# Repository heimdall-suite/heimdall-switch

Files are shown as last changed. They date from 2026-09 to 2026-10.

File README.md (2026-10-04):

# heimdall-switch

Wireless power switch node for RC vehicles, part of the [Heimdall Suite](../heimdall-kickoff.md).

Controlled from `heimdall-module` over BLE, independent of the vehicle's
normal RC control link (e.g. CRSF) — this switch has its own out-of-band
radio path so it keeps working regardless of the state of the main control
link. It originated as a replacement for a boat's Jeti SPS-20 magnetic
switch, but is built as a generic building block (not a single-purpose
commercial part like Jeti's RCPS10) so the same design serves any RC
vehicle — boat, plane, car — needing a remotely switched load.

## How it's triggered

```mermaid
flowchart LR
    TX["EdgeTX transmitter<br/>Lua widget or OneClick"]
    BTN["Local button<br/>on the switch node"]
    MOD["heimdall-module<br/>external RF module (ESP32-C3)"]
    SW["heimdall-switch<br/>nRF52 node"]
    LOAD["Switched load"]

    TX -- "S.Port" --> MOD
    MOD -- "BLE command (absolute ON/OFF)" --> SW
    SW -- "MOSFET (fail-on)" --> LOAD
    SW -- "BLE ack burst" --> MOD
    MOD -- "S.Port telemetry (ack)" --> TX
    BTN -. "5-15s: toggle, 15s+: pair" .-> SW
```

The transmitter side (Lua widget or a OneClick action) sends the command
through `heimdall-module`, the external RF module in the transmitter's
module bay; `heimdall-module` relays it over BLE to `heimdall-switch`,
which drives the MOSFET and acks back the same path so the widget can
show "Hello" / "Goodbye" / "No response". The node also has a local button
for manual toggling and pairing, independent of that whole chain.

## Docs

- [.docs/hardware.md](.docs/hardware.md) — MCU, power, switching stage,
  feedback, button/LED, open hardware items
- [.docs/protocol.md](.docs/protocol.md) — BLE roles, pairing, runtime
  cycle, command/ack frame layouts, the transmitter-side Lua widget
- [.docs/persistence.md](.docs/persistence.md) — what's kept in flash
  across power loss (state + replay counter) and the wear-levelling scheme
- [.agents/AGENTS.md](.agents/AGENTS.md) / [CLAUDE.md](CLAUDE.md) —
  instructions for AI coding agents working in this repo
- [hardware/kicad/](hardware/kicad/) — first-draft KiCad schematic (see
  `.docs/hardware.md`'s Schematic section for what's in it and what's
  still a placeholder)

## Status

No firmware yet. nRF52 toolchain (nRF5 SDK vs. nRF Connect SDK/Zephyr vs.
upstream Zephyr) is not yet decided. `src/` is a placeholder until that's
settled. A first-pass schematic exists under `hardware/kicad/`.

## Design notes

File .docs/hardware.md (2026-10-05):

# Hardware

- **MCU**: nRF52 — nRF52-DK or Adafruit Feather nRF52 Bluefruit for dev;
  production target is the **Fanstel BT832** module (nRF52832, 14×16×1.9mm,
  integrated PCB trace antenna, no custom RF layout needed). Chosen over the
  smaller Insight SiP ISP1507 (8×8×1mm) specifically for assembly: the
  ISP1507 is a 62-pad bottom-only LGA with no side access, which needs
  stencil+paste reflow — not viable for hand rework. The BT832 instead
  breaks out 16 pins as **castellated edges** (side-accessible, and per
  Fanstel's own datasheet, "SMT equipment is not required for soldering
  castellated pins"), backed by 24 further LGA-only pins for full 32-GPIO
  access if ever needed. Every signal this design needs — VDD, GND,
  SWDCLK/SWDIO/RESET for programming, plus 2 analog-capable GPIOs
  (P0.02/AIN0, P0.03/AIN1) and enough spare digital GPIOs for the output
  OFF-hold drive, ADC feedback, the button interrupt, and the status LED —
  lands on those 16 castellated pins, so the LGA-only pads never need to be
  used. A same-footprint BT832F variant (15×20.8×1.9mm, ~760m vs ~110m
  range) exists if longer BLE range is ever needed; not required for this
  short vehicle-to-module link, so BT832 is the default unless that changes.
- **Radio**: BLE. Chosen over ESP-NOW/WiFi-class radios (too power-hungry to
  listen continuously, ~mA-range RX current with no good sleep/wake story)
  and over sub-GHz CC1101 (lower idle current in theory, but needs its own
  antenna design and a second discrete radio chip — not worth it once
  duty-cycle math showed BLE was already more than adequate).
- **Power**: 2S-3S LiPo (~6-12.6V) off the vehicle's own power bus. Regulator:
  **TI TPS629206** (verified against the actual datasheet — 3-17V in, 4µA
  typical IQ, 0.6A max output — same TPS6292xx low-IQ family as the
  originally-considered TPS62901, ~30x this design's actual peak draw) —
  single stage is sufficient; a pack this size (1500-2500mAh) gives years
  of idle life even at a few µA, so don't over-engineer the regulator stage
  further. Chosen over the TPS62901 specifically for assembly: TPS62901 is
  only offered in a 9-pin VQFN-HR (0.5mm pitch, no-lead, recessed pins —
  reflow/hot-air-only with no visible solder joint), while the TPS629206 is
  in an **8-pin SOT-5X3 (1.6×2.1mm) with genuine gull-wing leads** (confirmed
  from the package outline's lead foot-angle dimensions) — same 4µA
  efficiency, no assembly trade-off. Full reference-design BOM below.
- **Switching element**: single high-side P-FET, **fail-on** — see
  [Switching stage](#switching-stage) below. No mechanical or coil relays.
  State across power loss is kept in flash
  ([persistence.md](persistence.md)), the same approach the Jeti SPS-20
  takes (MCU-driven FET switch with remembered state).
- **Feedback**: resistor divider on the switched (load-side) output into an
  ADC pin, to confirm actual delivered power downstream — not just "we sent
  a pulse."
- **Local button**: debounced, GPIOTE interrupt-wake (must wake the nRF52
  from deep sleep independent of the normal BLE scan cycle). Held ≥5s but
  <15s → toggle power state locally. Held ≥15s → enter pairing mode.
- **Status LED**: 1 GPIO, visual state indicator. Must be clearly visible
  **outdoors in sunlight**, typically through a 3mm hole drilled in the
  hull/fuselage (as with the Jeti SPS-20's daughter-board LED). So: 3mm
  through-hole, water-clear lens, narrow beam, high intensity — **Kingbright
  L-7104ZGCK**, InGaN green 525nm, 8cd min / 14cd typ at 20mA, 30° (see
  [BOM](#bom)). Originally the Everlight 204-10SUGC/S400-A4 (3.2cd, 20°),
  which went out of stock at TME and Mouser; it's still the LCSC alternative.
  - **Driven from VBAT, not 3.3V**: high-intensity green/blue/white LEDs
    (InGaN) need ~3.0-3.4V forward, which leaves nothing across a
    resistor on the 3.3V rail. Circuit, **high-side switched** so the
    LED's cathode can go straight to GND (3 daughter-board wires, not 4):
    VBAT → Q6 (BSS84 P-FET) → R_LED (680Ω 1206) → LED → GND. Q6's gate is
    pulled up to VBAT by R_Q6_PU (1MΩ) and pulled to GND by Q5 (AO3400A)
    when P0.03 (`LED_DRV`) is high, giving Q6 |V_GS| = full pack voltage
    (within BSS84's ±20V). R_LED_PD (1MΩ) holds Q5 off while the MCU is
    in reset or dead. Plain GPIO drive; no high-drive mode needed. Cost:
    ~6-13µA through R_Q6_PU *only while the LED is lit*; nothing when off.
    Q6 is the same part as Q2 and Q5 as Q1, so no new part numbers.
  - **Current follows pack voltage** (V_F ≈ 3.1V at these currents):
    ~4.3mA at 6.0V (2S LiFePO4 near empty), ~5.1mA at 6.6V (2S LiFePO4
    nominal), ~7.8mA at 8.4V (2S LiPo full), ~14mA at 12.6V (3S full) —
    roughly 1.7-10cd with the L-7104ZGCK (intensity is linear in current
    on its datasheet curve; 25mA max), far above a normal indicator. R_LED
    dissipates ≤0.13W. If an even brightness matters, firmware can PWM
    the LED against the pack voltage it reads through ADC_FB while the
    output is ON.
  - **Short protection**: Q6 and R_LED sit on the main board ahead of J4, so a
    daughter-board wire shorted to GND draws at most 12.6V / 680Ω =
    18.5mA (0.23W, within the 1206's 0.25W).
- **Breakout for a daughter board (J4)**: LED and button can sit on the
  main board (LED1/SW1 fitted) or on a small daughter board, positioned
  wherever the vehicle needs them. J4 is a 3-pin **JST-GH** header
  (SM03B-GHS-TB, 1.25mm pitch, right-angle SMD at the board edge; 1 LED_A,
  2 BTN, 3 GND — the LED cathode and the
  button share the GND wire) wired in parallel with LED1/SW1. In the main
  schematic LED1/SW1 are the *optional on-board positions*; for off-board
  use leave them unfitted and plug a ready-made 3-wire GH cable
  (pin 1 ↔ pin 1) from J4 to the daughter board's GH header. Q5, Q6 and
  R_LED stay on the main board, so the daughter board only needs the LED
  and the switch. See [Daughter board](#daughter-board-ui).
  **R_BTN (1kΩ)** in
  series with P0.20 protects the pin from ESD on the off-board wire (the
  button is the part people touch); with the internal pull-up (~13kΩ) the
  pressed level is ~0.23V, a clean logic low.

## Pin assignment (BT832 castellated edge)

All 16 castellated pins are used or reserved; the 24 LGA-only pads are
untouched. Programming pins (VDD/GND/RESET/SWDCLK/SWDIO) are covered in
[protocol.md](protocol.md)'s scope — this table is the full picture:

| Pin | Net | Function |
|---|---|---|
| 1 | P0.26 | Spare GPIO (was the LED drive; moved to P0.03 so PCB traces from this pin row don't cross the crystal) |
| 2 | P0.27 | Spare GPIO |
| 3 | P0.00/XL1 | 32.768kHz crystal (LFCLK) |
| 4 | P0.01/XL2 | 32.768kHz crystal (LFCLK) |
| 5 | P0.02/AIN0 | ADC feedback (load-side sense divider) |
| 6 | P0.03/AIN1 | Status LED drive (`LED_DRV`, Q5 gate; high = LED on) |
| 7 | P0.09 | Spare GPIO (NFC pin — needs `NFCPINS` UICR cleared to use as GPIO) |
| 8 | P0.10 | Spare GPIO (NFC pin — needs `NFCPINS` UICR cleared to use as GPIO) |
| 9 | VDD | Power |
| 10 | GND | Ground |
| 11 | P0.13 | Output OFF-hold (high = output OFF, released = ON) |
| 12 | P0.18 | SWO (trace output to J1 pin 6) |
| 13 | P0.20 | Button input (GPIOTE, must wake from System OFF) |
| 14 | P0.21/RESET | SWD reset |
| 15 | SWDCLK | SWD clock |
| 16 | SWDIO | SWD data |

Notes:
- **LFCLK**: the module's mandatory 32MHz radio crystal is already onboard
  the BT832 (not exposed on any pin). Pins 3/4 are for the *optional*
  32.768kHz LFCLK crystal. It is **not required**: this node only scans
  and advertises (no BLE connections), and neither needs better than the
  internal RC oscillator's ±500ppm — drift over a 2.5s wake interval is
  ~1ms. The crystal is a small idle-power optimization (Fanstel's datasheet
  recommends it "for lower power consumption at idle state"): the RC
  oscillator draws more (~0.6µA vs ~0.25µA for the crystal oscillator,
  nRF52832 PS typicals — verify) and needs periodic calibration against
  the 32MHz crystal (cheap here: it can piggyback on the scan wake-ups).
  Net saving ~0.4-0.7µA, i.e. 1-2% of the ~34µA OFF budget — hard to
  justify on power alone. **Decision: Y1/C1/C2 stay in the design;
  whether to fit them is decided at assembly.** Firmware must therefore
  support both LFCLK sources (LFXO and calibrated LFRC), ideally
  detecting which is present; with the crystal fitted, the real
  difference can be measured at bring-up. Part: **Epson FC-135** 32.768kHz, CL 12.5pF, ±20ppm
  (3.2×1.5mm, Mouser FC-135 32.7680KA-A5 / LCSC C32346 (JLCPCB basic);
  the 9pF variant isn't stocked),
  with C1 = C2 = **18pF C0G**: nRF52 formula C = 2·CL − C_pin (4pF) −
  C_pcb (~1-2pF) ≈ 19-20pF → nearest E12 below.
- **DC/DC**: the two inductors for the nRF52832's internal DC/DC regulator
  are inside the BT832 module (per Fanstel's datasheet), so firmware can
  enable DC/DC mode — the lower-current figures in the power budget apply.
- **P0.09/P0.10** default to NFC antenna function at reset; firmware must
  clear the `NFCPINS` UICR register once to use them as plain GPIOs. No
  hardware-side implication, just a firmware bring-up step to remember.
- Programming header: pins 9/10/14/15/16 (VDD/GND/RESET/SWDCLK/SWDIO) are
  grouped on the same edge of the module — worth breaking out to a small
  pogo-pin test-jig footprint or header for repeated flashing during
  bring-up, rather than hand-wiring each time.
- **SWD header J1**: the standard **ARM Cortex Debug 10-pin** connector
  (2×5, 1.27mm pitch), male pins on the board, the probe's ribbon cable
  brings the female socket. J-Link, ST-Link, the Raspberry Pi Debug
  Probe, CMSIS-DAP probes and Nordic DKs' debug-out all plug straight in.
  **hanxia HX PZ1.27-2x5P TP** (SMD, LCSC C41376037, ~$0.10), a generic
  2×5 1.27mm SMD header. The Samtec FTSH-105-01-L-DV-K (C5155080) that
  ARM's spec references is the same thing at ~$1.46. Its recommended land
  pattern (0.74 × 2.50mm pads, 6.50mm overall) matches KiCad's
  `PinHeader_2x05_P1.27mm_Vertical_SMD` (0.74 × 2.40mm, 6.30mm overall,
  same 1.5mm gap between rows) closely enough to keep the stock
  footprint. Ordered part: **Connfly DS1031-08-2\*5P8BS41-3A** (TME
  ZL322-2X5P), since TME doesn't carry the hanxia. Its recommended land
  pattern (0.60 × 2.45mm pads, 1.60mm between rows, 6.50mm overall, tails
  spanning 5.7mm) is also within ~0.1mm of the stock footprint, and the
  drawing has no locating pegs (only an optional pick-up cap). Fitted on
  **every** board: each one needs SWD at least once
  to flash the bootloader, and later for recovery. It's unshrouded, so
  the cable can go on either way round: pin 1 is marked on the
  silkscreen, match it to the ribbon's red stripe. Programmer: the nRF52
  DK's Debug out (P19, same 10-pin connector) or any J-Link/CMSIS-DAP
  probe, with a plain 10-pin 1.27mm ribbon cable.

  | J1 pin | Signal | BT832 pin |
  |---|---|---|
  | 1 | VTref (+3V3) | 9 (VDD) |
  | 2 | SWDIO | 16 |
  | 3, 5, 9 | GND (9 = GNDDetect) | 10 |
  | 4 | SWCLK | 15 |
  | 6 | SWO | 12 (P0.18) |
  | 7 | KEY (no pin function) | — |
  | 8 | NC/TDI (not connected) | — |
  | 10 | nRESET (10k pull-up R_RST to +3V3) | 14 (P0.21/RESET) |

  SWO is the nRF52832's trace output, fixed to P0.18 in silicon: wiring
  it gives printf-style logging over the debug probe (e.g. SEGGER SWO
  viewer) without a UART. P0.18 was spare, so it costs nothing.

  Pin 1 is a **voltage reference for the probe, not a power input** — power
  the board from its battery while flashing. A probe set to *supply*
  3.3V with no battery connected back-feeds through the buck onto VBAT,
  and with fail-on Q3 then puts ~3V on the load output.
- 4 spare GPIOs remain (1, 2, 7, 8) if anything else comes up.
- P0.13 must be driven to its saved state as early as possible in boot —
  see [Switching stage](#switching-stage).

## Switching stage

**Load**: receiver, GPS, 4 micro/mini servos, 2 standard servos, on 22-24
AWG leads. ~2-3A continuous, ~6-8A peaks for tens of ms (servos
starting/stalling together). Output is raw pack voltage (up to 3S /
12.6V) — with 3S, a BEC sits downstream of the switch. Nothing else may
feed the output side (no receiver-side battery, no ESC BEC red wire): a
single FET's body diode conducts output→input when off, so back-feed would
defeat the switch. Back-to-back FETs were considered and dropped for this
reason — not needed as long as that rule holds.

**Fail-on principle**: a control-side failure must never kill the output
— losing power in flight/on the water means losing the vehicle. The
hardware default is therefore ON, and the MCU must *actively hold* the
output OFF. The realistic failure causes are firmware hangs, brownout
resets, vibration-cracked solder joints, regulator failure — spontaneous
silicon failure is negligible by comparison — and all of these fall back
to ON. Only a failure in the power path itself (the FET, its gate
pull-down) can drop the output; MOSFETs typically fail short (ON), which is
the benign direction.

**Circuit**:
- **Q3 — load switch**: P-FET, source to VBAT, drain to LOAD_OUT.
  **Selected: AOS AO4407A** (SO-8, LCSC C16072) — −30V V_DS, ±25V V_GS,
  R_DS(on) ≤ 13mΩ at V_GS = −10V, ≤ 17mΩ at −6V (12.7mΩ typ), V_GS(th)
  −1.7 to −3.0V. It is *not* specified at −4.5V, and doesn't need to be:
  the gate is pulled all the way to GND, so |V_GS| = pack voltage, never
  below ~5V on 2S (≈14mΩ typ there per datasheet Fig. 5). Worst case at
  3A ≈ 0.15W; peaks ~1W for ms — fine in SO-8 with a copper pad. Chosen
  over the DFN 3×3 AONR21357 (C431196, ≤12.3mΩ at −4.5V) for easier hand
  assembly/inspection on pre-production boards — AONR21357 is the drop-in
  electrical upgrade if the board is shrunk later. AO4409 (SO-8, −4.5V
  spec) rejected: obsolete. SOT-23 parts (typically 40-60mΩ) run too hot
  at 3A continuous.
- **Gate default ON**: Q3 gate pulled to GND by R_PD1 ‖ R_PD2 (2×2.2MΩ =
  1.1MΩ), split so a single open resistor can't leave the gate floating.
- **Slow turn-on**: C_SS = 220nF gate-source with the 1.1MΩ pull-down →
  τ ≈ 240ms. On battery connect or MCU reset the gate starts at V_GS = 0;
  Q3 only starts conducting once V_GS crosses its threshold. Simulated
  (see [Verification](#verification-simulation-and-copper)) across the
  AO4407A's threshold spread (−1.7 to −3.0V): **40–70ms after power-up at
  12.6V, 60–115ms at 8.4V** (AOS's own model: 92 / 153ms). The MCU must
  assert OFF before that — the firmware requirement stays **within ~20ms
  of power-up** (bare nRF52 boot to GPIO is a few ms), leaving ≥2× margin.
  Q3 then passes through its linear region in ~12–40ms, fully on after
  ~75ms at 12.6V / ~115ms at 8.4V.
  The same RC soft-starts the inrush into the downstream
  BEC/receiver/servo capacitance.
  C_SS is a **50V X7R 0805** (Samsung CL21B224KBFNNNE, LCSC C5378), not a
  25V 0603: it sits at up to 12.6V, and a 25V 0603 X7R loses ~30% of its
  capacitance there, cutting the delay by about as much. The 50V 0805
  part loses ~10%. Don't reduce C_SS: 100nF would bring the worst case
  down to ~19ms, inside the firmware window (simulated).
- **Active OFF**: Q2 (P-FET) clamps Q3's gate to VBAT through R_LIM when
  on. Q2's gate is pulled up to VBAT by R_CLAMP_PU (1MΩ) and pulled low by
  Q1 (N-FET), driven from P0.13 via R_G1 (100Ω), with R_OFF_PD (1MΩ)
  holding Q1 off whenever the GPIO floats (reset, unpowered MCU). GPIO
  high → Q1 on → Q2 on → output OFF. Turn-off is fast (~30–40µs,
  simulated); only turn-on is slowed.
  - **Q1: AOS AO3400A** (SOT-23, LCSC C20917, JLCPCB basic part) —
    logic-level (V_GS(th) 0.65-1.45V), fully on from a 3.3V GPIO. The CJ
    2N7002 (C8545, V_GS(th) up to 2.5V) was the placeholder: works, but
    thin margin at 3.3V drive.
  - **Q2: Nexperia BSS84** (SOT-23, LCSC C493579) — V_GS(th) −0.8 to
    −2.0V, I_DSS ≤ 100nA at −40V/25°C. A *high* threshold is deliberate:
    the more gate voltage Q2 needs, the more Q1 leakage it takes to turn it
    on by accident (so low-threshold parts like AO3401A are unsuitable
    here). **Ordered: Nexperia BSS84AK** (TME; the BSS84 is out of stock
    at TME and Mouser, and Mouser lists it as not recommended for new
    designs): same SOT-23 G/S/D pinout, V_GS(th) −1.1 to −2.1V (higher, so
    better here), ±20V V_GS, ESD-protected gate (I_GSS ≤ 10µA at ±20V,
    which only flows while Q1 holds the gate low). Its I_DSS spec is
    looser — ≤ 1µA at −50V/25°C, ≤ 2µA at 150°C — still below the ≈3-9µA
    step (2) below needs, but one more reason to do the first-board check.
  - **R_LIM (100Ω, Q2 drain → Q3 gate)**: when Q2 switches on it shorts
    C_SS (charged to VBAT); without R_LIM the discharge spike is ~1A+ for
    ~µs, above BSS84's ~0.5A pulse rating (tiny energy, ~17µJ — a spec
    violation rather than a likely failure). R_LIM caps it at ~0.1A;
    turn-off goes from ~2µs to ~20µs, irrelevant for this load.
- **Leakage margin for fail-on**: with the MCU dead, a chain of leakages
  would have to (1) pull Q2's gate ~0.8-1V below VBAT — ≈1µA of Q1
  leakage through R_CLAMP_PU — and then (2) push ≈3-9µA through Q2 into
  Q3's gate against R_PD (1.1MΩ) to lift it within ~3V of VBAT. Small
  SOT-23 FETs typically leak tens of nA at 7-13V and warm temperatures:
  10-100× margin. Datasheet worst cases (often "1µA max" at full rated
  V_DS) are looser, so **verify on the first boards**: MCU unpowered,
  output ON — Q3 gate should read within a few mV of GND and Q2 gate
  within a few mV of VBAT. Don't raise R_CLAMP_PU / R_PD further to save
  current without re-checking this.
- **Gate protection**: D_Z, 18V zener gate-source on Q3 (cathode to VBAT)
  — **MMSZ5248B** (SOD-123; ordered from DC Components via TME, LCSC
  C2127 is JSCJ's). At 12.6V max the ±25V gate
  is within spec without it; it's cheap insurance against transients.
  18V rather than 15V because the zener sits reverse-biased at full pack
  voltage whenever the output is ON, and its leakage flows into Q3's gate
  node against R_PD: a 15V zener at 12.6V (84% of V_Z) is near its knee
  and can leak µA, lifting the gate; the 18V part is specified at
  ≤100nA at 14V (≤0.11V gate lift through 1.1MΩ), and still clamps well
  below the 25V gate rating.

**Reverse polarity protection**: servo-style RC plugs are easy to insert
backwards, and a reversed pack would destroy not just this node but the
load — Q3's body diode would conduct and put reversed voltage across the
receiver/servos. So the protection covers the whole power path, right at
the battery input:
- **Q4**: P-FET "ideal diode" in the positive line between J3 and the VBAT
  rail — drain to the battery (+) pin of J3, source to VBAT, gate to GND
  via R_REV (100kΩ), plus an 18V gate-source zener (D_Z2, cathode to
  source, same MMSZ5248B) like Q3's. **Same part as Q3: AO4407A** (SO-8, LCSC C16072).
- Correct polarity: Q4's body diode conducts first, lifting its source to
  ~VBAT, which pulls V_GS to −VBAT and turns it fully on. Reversed: the
  body diode is reverse-biased and V_GS ≈ 0, so Q4 stays off and nothing
  downstream sees negative voltage.
- Cost: zero quiescent current (no DC path below the zener voltage);
  ~135mW / ~45mV extra drop at 3A. A series Schottky was rejected — fine
  for the node's µA supply, but ~1.2W at 3A in the load path.
- Q4 only blocks *reverse polarity*. Once on, it conducts both ways, so it
  doesn't block back-feed from the output side — that's still ruled out by
  the "nothing else feeds the output" rule above.
- Out of scope: a reversed *load-side* connector (J2) can't be protected
  here — that's the load's own wiring.

**Cost of fail-on**: see [Power budget](#power-budget) — ~15µA extra while
OFF. A dead MCU while OFF turns the output ON, so a stored vehicle with the
battery connected could power up and drain the pack — **disconnect the
battery for storage** (standard practice; Jeti's SPS-20 manual says the
same).

**Firmware requirements** (see also [persistence.md](persistence.md)):
- Restore the saved state to P0.13 early in boot — within ~20ms of
  power-up, before Q3 starts conducting (see Slow turn-on).
- **Watchdog is mandatory**: firmware hung with P0.13 held high is the one
  failure the hardware default can't cover. The nRF52 WDT (LFCLK-clocked,
  can't be stopped once started) resets the MCU, which releases P0.13 →
  output falls back to ON → firmware restores the saved state.

## Power budget

Estimates, not measurements — every radio/MCU figure here needs checking on
real hardware. Reference pack: **1500mAh 2S LiFePO4 RX pack (6.6V
nominal)**. Resistor currents scale with pack voltage (roughly ×1.9 on 3S).

**Assumptions**:
- TPS629206 quiescent 4µA (datasheet typical).
- nRF52832 System ON sleep, RTC + 32kHz crystal, RAM retained: ~2µA.
- Scan cycle per [protocol.md](protocol.md): wake every 2.5s, 7.5ms scan
  window + ~1.5ms wake overhead at ~6.5mA (radio RX with the nRF52's
  internal DC/DC enabled — the BT832 has the DC/DC inductors onboard) →
  ~23µA average. LDO-mode figures below are kept only as the fallback if
  DC/DC is left disabled in firmware (RX roughly doubles → ~45µA).
- Buck efficiency at these µA loads ~85% → a 3.3V-side current appears at
  the pack as ×0.59 (3.3V / (6.6V × 0.85)).

**Always on (both states)**, at the pack:

| Item | 3.3V side | At pack |
|---|---|---|
| TPS629206 quiescent | — | 4µA |
| nRF52 sleep | 2µA | 1.2µA |
| BLE scan duty cycle | 23µA (LDO: 45µA) | 13.5µA (LDO: 26.5µA) |
| **Subtotal** | | **~19µA (LDO: ~32µA)** |

**Extra in OFF** (fail-on hold active):

| Item | Current |
|---|---|
| R_PD1‖R_PD2 across VBAT (Q2 clamping) | 6.6V / 1.1MΩ = 6.0µA |
| R_CLAMP_PU across VBAT (Q1 on) | 6.6V / 1MΩ = 6.6µA |
| R_OFF_PD on the 3.3V GPIO | 3.3µA → 1.9µA at pack |
| ADC divider (output is 0V) | 0 |
| **OFF total** | **~34µA (LDO: ~47µA)** |

**Extra in ON**: the gate network draws nothing (Q1/Q2 off, Q3 gate at
0V). The ADC divider (100k + 33k across LOAD_OUT) draws 6.6V / 133kΩ =
50µA → **ON total ~69µA** for the node itself. That's irrelevant next to
the load (receiver + GPS + 6 idle servos ≈ 150-200mA), but could drop to
~5µA with a 1M/330k divider if it ever matters (needs a longer SAADC
acquisition time for the higher source impedance).

**Storage time, OFF, battery left connected** (1500mAh pack, counted down
to 20% remaining = 1200mAh usable):

| Case | Drain | Time to 20% |
|---|---|---|
| Node only, DC/DC | 34µA | ~35,000h ≈ **4 years** |
| Node only, LDO | 47µA | ~25,500h ≈ **2.9 years** |
| Node + LiFePO4 self-discharge (~2%/month ≈ 41µA equivalent), DC/DC | ~75µA | ≈ **1.8 years** |
| For comparison: Jeti SPS-20 (160µA OFF, per its manual), node only | 160µA | ≈ 10 months |

The node's OFF draw is about the same as the pack's own self-discharge, so
leaving the pack connected costs roughly half its shelf life — acceptable,
but "disconnect for storage" still stands, mainly because of the fail-on
case above. Left **ON** by mistake, the same pack is flat in ~6-8h from
the idle load alone; the switch's own draw doesn't matter there.

Biggest levers if OFF draw needs to drop: the scan interval (2.5s → 5s
halves the ~13.5µA scan share) and the fail-on hold resistors (limited by
the leakage constraint above).

## Schematic

**Circuit at a glance** (each block is also labelled on the schematic
sheet). Four ideas explain most of it: a P-FET turns on when its gate is
pulled well below its source; an N-FET pulling a P-FET's gate down lets
a 3.3V GPIO switch a 12V path (Q1/Q2, Q5/Q6); the 1-2.2MΩ resistors set
the safe default when the MCU isn't driving (output ON, LED off); the
rest is supply plumbing.

| # | Block | Parts | Job |
|---|---|---|---|
| 1 | Battery in + reverse polarity | J3, Q4, R1, D1 | Q4 is an ideal diode: body diode lifts VBAT, R1 pulls the gate to GND, Q4 turns fully on; a reversed pack leaves it off. D1 clamps V_GS. |
| 2 | Load switch (fail-on) | Q3, R9, R10, C7, D2 | Q3 is the switch. R9 ‖ R10 hold it ON by default, C7 slows turn-on (gives the MCU time after reset), D2 clamps V_GS. |
| 3 | Switch-off circuit | Q1, R5, R6, Q2, R7, R8 | P0.13 high → Q1 on → Q2 on → R8 pulls Q3's gate to VBAT → output OFF. R6/R7 keep the chain idle when the MCU is dead. |
| 4 | Load out + voltage sense | J2, R11, R12, C8 | R11/R12 scale LOAD_OUT to the ADC (12.6V → 3.1V), C8 filters: pack voltage while ON, ~0V while OFF. |
| 5 | 3.3V regulator | R2, C3, U2, R3, L1, C4 | R2 + C3 damp the plug-in spike; U2 buck with L1/C4; R3 sets its mode. |
| 6 | MCU | U1, C5, C6, Y1, C1, C2, R4, J1 | BT832 (nRF52832 + antenna), supply decoupling, 32kHz crystal, reset pull-up, SWD header. |
| 7 | Status LED + button | Q5, Q6, R13, R14, R15, LED1, SW1, R16, J4 | P0.03 high → Q5 pulls Q6's gate low → Q6 feeds VBAT through R14 to the LED (off by default). SW1 to GND with R16 protecting the pin. J4 breaks LED/BTN/GND out to the daughter board. |

The KiCad schematic implementing everything on this page lives in
[hardware/kicad/](../hardware/kicad/) (`heimdall-switch.kicad_pro` +
`.kicad_sch`), with a rendered [heimdall-switch.svg](../hardware/kicad/heimdall-switch.svg)
for quick viewing without opening KiCad. The BT832 and TPS629206 symbols
are project-local, in `heimdall-switch.kicad_sym` (resolved automatically
via the project's `sym-lib-table`). Neither part is in KiCad's own
libraries (they have the bare nRF52832 chip, not the module), but both
have vendor symbols: Fanstel publishes a KiCad library with the BT832
([hemalchevli/Fanstel-kicad-library](https://github.com/hemalchevli/Fanstel-kicad-library),
linked from Fanstel's site; KiCad 5 format) and TI's TPS629206 symbol is
available through Ultra Librarian. Ours were drawn before those were
found and kept: the BT832 symbol's pin map is identical to Fanstel's
(checked pin by pin, see the footprint note below) and its pins sit on
KiCad's 2.54mm grid.

Drawn with real wires within each block (regulator, MCU + crystal/SWD,
status LED + button + J4 breakout, switching stage + load output), KiCad power symbols (`GND`,
`+3V3`, `VBAT` — the latter is the stock `+BATT` symbol renamed) with
PWR_FLAGs, and no-connect markers on the intentionally-open pins
(VSET/PG, spare GPIOs). Signals cross between blocks as net labels:
`OUT_OFF` (P0.13 → switching stage), `ADC_FB` (divider → P0.02),
`LED_DRV` (P0.03 → Q5 gate), `BTN` (P0.20 → R_BTN/SW1/J4), and the debug
signals `nRESET`, `SWDCLK`, `SWDIO`, `SWO` (U1 → J1).
Within the LED/button block, the `LED_A` label carries the LED anode to
J4.
J3 is the battery input connector.

Verified with `kicad-cli sch erc`, netlist export (every pin checked
against the intended net) and `sch export svg` (kicad-cli is installed
but not on PATH — `AppData/Local/Programs/KiCad/10.0/bin/`). ERC: **0
errors, 0 warnings**. All custom-symbol pins (BT832, TPS629206) sit on
the 2.54mm grid — keep it that way when editing `heimdall-switch.kicad_sym`:
an off-grid pin makes GUI-drawn wires snap past it and silently not
connect (this happened once, to SWDCLK/SWDIO).

Sheet layout: the reverse polarity block (J3 → Q4 → VBAT, with D_Z2 and
R_REV) sits on its own below the regulator and connects to it through the
`VBAT` power symbol; J3's pin 1 net is labelled `BATT+`. The debug
header J1 (with R_RST) sits in its own block right of the crystal,
linked to U1 by labels, so no wires cross.

Reading the schematic:
- **Power symbols** (`VBAT` arrow, `+3V3` arrow, `GND`) connect by name
  across the whole sheet — two `VBAT` arrows are the same net even with no
  wire between them.
- **PWR_FLAG** (small diamond, text hidden) is not a component and not in
  the BOM. It tells ERC "this net is powered from outside" — needed where
  power arrives through pins KiCad sees as passive (battery connector, Q4,
  L1, R_IN). One each on VBAT (at Q4), GND (at J3), +3V3 (at C_OUT) and
  the regulator input node after R_IN.
- One GND symbol has its "GND" text hidden where it collided with
  wires (U2 pin 5) — an ordinary GND connection.

**Annotation and footprints**: the schematic is annotated with standard
references and every part has a footprint. The design notes on this page
keep the descriptive names (`R_PD1`, `C_SS`, …); each renamed symbol
carries its old name in a hidden `Function` field, and the mapping is:

| Ref | Name in these docs | Ref | Name in these docs |
|---|---|---|---|
| C3 | C_IN | R7 | R_CLAMP_PU |
| C4 | C_OUT | R8 | R_LIM |
| C5 | C_VDD1 | R9 | R_PD1 |
| C6 | C_VDD2 | R10 | R_PD2 |
| C7 | C_SS | R11 | R_FB_TOP |
| C8 | C_FB | R12 | R_FB_BOT |
| R1 | R_REV | R13 | R_Q6_PU |
| R2 | R_IN | R14 | R_LED |
| R3 | R_MODE | R15 | R_LED_PD |
| R4 | R_RST | R16 | R_BTN |
| R5 | R_G1 | D1 | D_Z2 |
| R6 | R_OFF_PD | D2 | D_Z |

Unchanged: C1/C2 (crystal caps), Q1–Q6, U1, U2, L1, Y1, LED1, SW1, J1–J4.
Footprints are KiCad stock (0603 passives; 0805/1206 where the BOM says;
SOT-23, SOIC-8, SOD-123, SOT-583-8, 1008, 3215 crystal, JST-GH, 2×5
1.27mm SMD header, solder-wire pads) except two project-local items:
- **`heimdall-switch:Fanstel_BT832`** (in `heimdall-switch.pretty`, via
  the project `fp-lib-table`), drawn from Fanstel's datasheet (Ver 2.12,
  p.8): 14.0 × 16.0mm module, 16 castellated pads at 1.10mm pitch, pins
  1–8 down the left side and 9–16 up the right, pin 8/9 1.10mm above the
  bottom edge. Pads are 0.70 × 1.75mm, reaching 0.75mm beyond the module
  edge (and 1.0mm under it) for the soldering iron. The 24 LGA pads are left off (unused; the
  module's LGA pads then sit on solder mask). A copper keep-out (tracks,
  vias, pads, pours, both layers) covers the 6.43mm antenna section.
  **Verified against Fanstel's official KiCad library**
  ([hemalchevli/Fanstel-kicad-library](https://github.com/hemalchevli/Fanstel-kicad-library),
  MIT, linked from Fanstel's site; footprint `BT832-BT832L`): all 16 pad
  centres match within 0.001mm (pitch, pin 8/9 height, pin 1 position),
  same 0.70mm pad width and the same 0.75mm overhang beyond the module
  edge (theirs is 1.50mm long, ours 1.75mm reaching 0.25mm further under
  the module). Their symbol's pin map matches ours pin for pin.
  3D model: Fanstel's STEP of the BT832 (Pro/E export), in
  `hardware/kicad/heimdall-switch.3dshapes/Fanstel_BT832.step`, attached
  to the footprint (rotated −90° about X, raised 0.3mm so the module's
  0.6mm PCB sits on ours); total height ~2.0mm.
- **`heimdall-switch:AO4407A`** symbol (in `heimdall-switch.kicad_sym`):
  the generic P-FET drawing with SO-8 pin numbers — G = 4, S = 1/2/3,
  D = 5–8, the duplicates stacked on the same pin — so Q3/Q4 map onto the
  stock SOIC-8 footprint without moving any wires.

Verified after the change: ERC 0/0; the netlist is identical net-for-net
(old references mapped, Q3/Q4 S/D pins expanded); every symbol pin has a
matching footprint pad. Every part with an LCSC number carries it in a
hidden `LCSC` field, so `kicad-cli sch export bom --fields
"Reference,Value,Footprint,LCSC"` gives an order list. The parts
actually ordered (TME + Mouser, see [BOM](#bom)) are in hidden
`Manufacturer`, `MPN`, `Supplier` and `Supplier PN` fields; export those
the same way for the TME/Mouser order lists. Where the ordered part is a
substitute, the `LCSC` field still names the original part as the LCSC
alternative.

Known simplifications in this draft, worth revisiting before layout:
- BT832 VDD decoupling (C5 4.7µF + C6 100nF, as on Fanstel's eval
  board) sits left of U1 on the sheet; on the PCB both sit at U1's VDD
  pin.
- The switching stage implements the fail-on design in
  [Switching stage](#switching-stage) (Q1 driver, Q2 gate clamp, Q3 load
  switch, R_LIM, R_PD1/R_PD2, C_SS, D_Z).
- **The KiCad file is now the source of truth.** `gen_body.sh` /
  `build_sch.sh` generated the first wired draft, but the schematic has
  since been rearranged in the GUI and patched (J1 layout, reverse
  polarity protection, gridded symbols) — the generator no longer matches
  it. Don't run `build_sch.sh`: it would overwrite all of that. Kept only
  as a record of how the draft was produced.
- ADC divider (R_FB_TOP=100k, R_FB_BOT=33k) assumes sensing a ~12.6V max
  load rail scaled to a safe ADC input; revisit once the actual load
  voltage range is known.

## PCB layout

**Rev 2** (current), in [hardware/kicad/](../hardware/kicad/)
(`heimdall-switch.kicad_pcb`). Views:
[top](../hardware/kicad/layout-top.png),
[bottom](../hardware/kicad/layout-bottom.png) (mirrored, as seen from
below), 3D [top](../hardware/kicad/render-top.png) /
[bottom](../hardware/kicad/render-bottom.png). Status: DRC 0 violations,
0 unconnected, full schematic parity; reviewed by eye in the KiCad GUI.
Rev 1 (53 × 23mm, power path on top) was never ordered; it stays in git
under the tag `main-pcb-rev1`.

| Top, angled | Bottom (power side), angled |
|---|---|
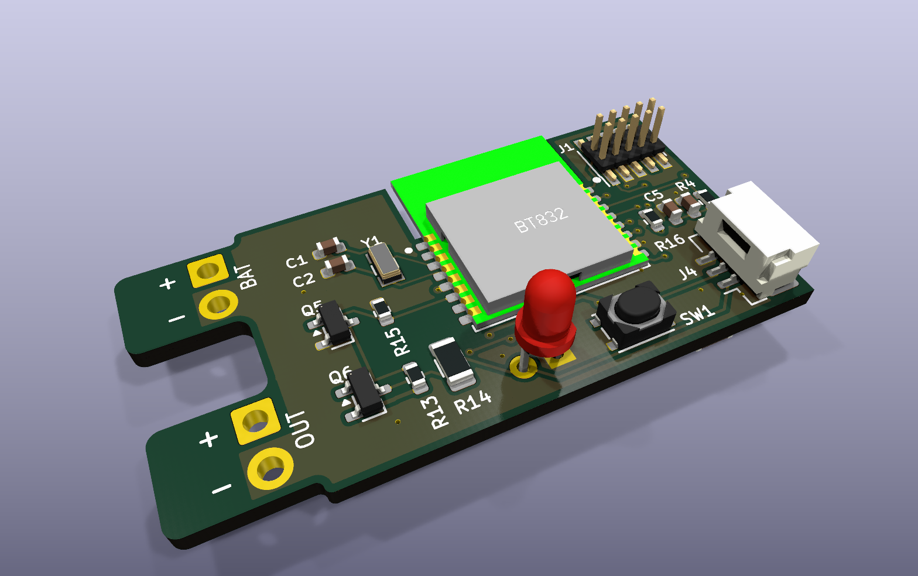
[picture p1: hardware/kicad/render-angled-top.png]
Main board, 3D top, angled
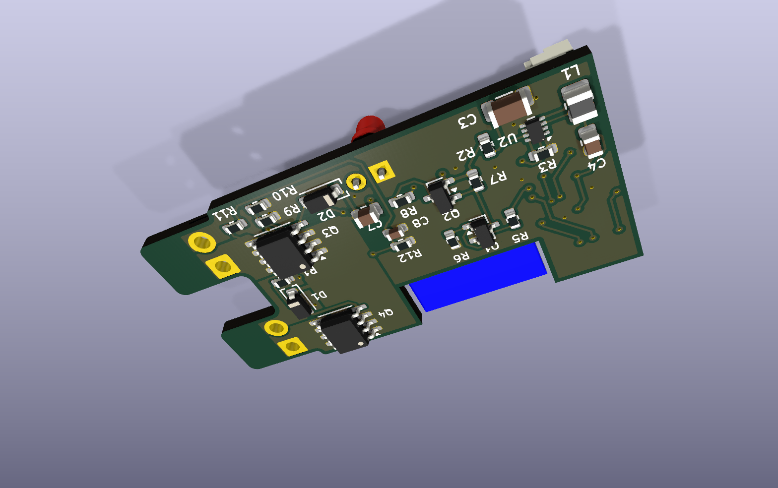
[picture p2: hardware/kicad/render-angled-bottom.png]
Main board, 3D bottom, angled
|  |  |

| Top | Bottom (mirrored, as seen from below) |
|---|---|
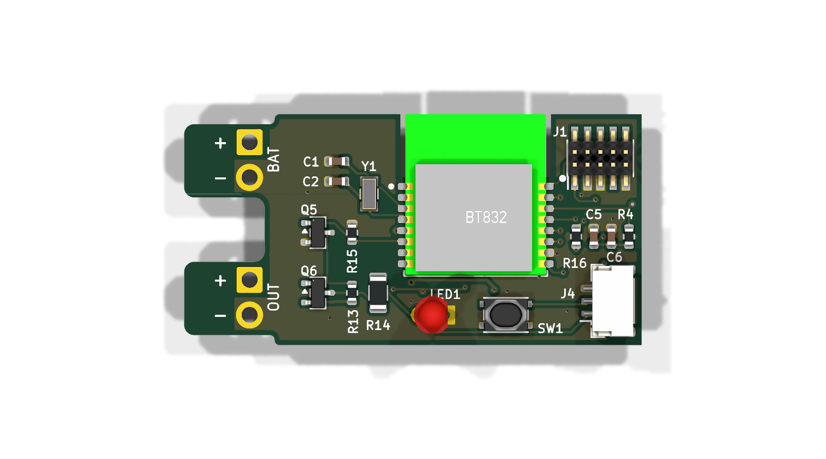
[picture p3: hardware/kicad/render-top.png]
Main board, 3D top
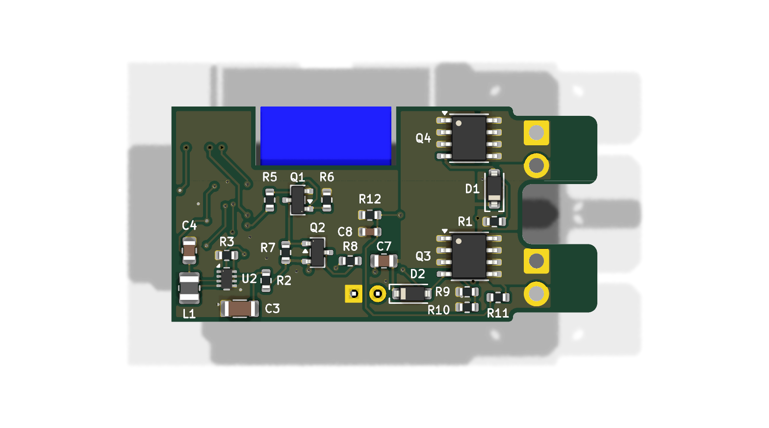
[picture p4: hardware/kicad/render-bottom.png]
Main board, 3D bottom
|  |  |
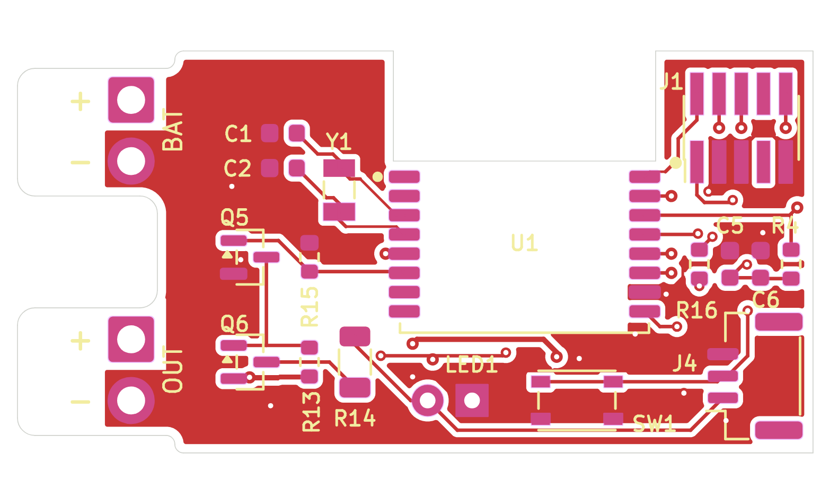
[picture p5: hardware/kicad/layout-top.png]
Main board layout, top
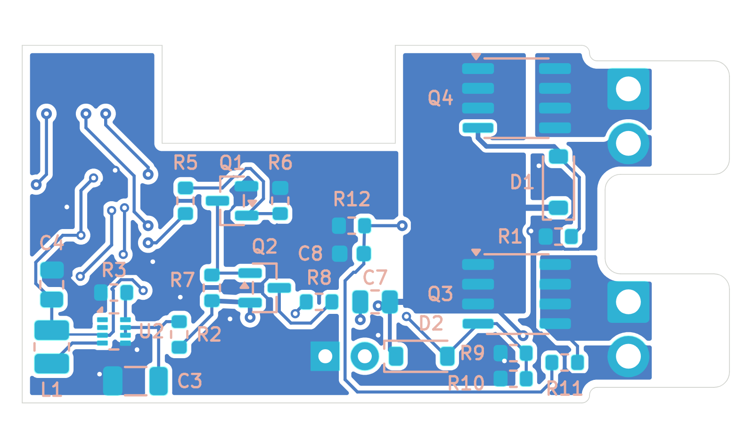
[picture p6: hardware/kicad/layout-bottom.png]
Main board layout, bottom
|  |  |

**Board**: 45.5 × 23mm, 2 layers, 1.6mm FR4, parts on both sides, laid
out in **zones by function**, like a high-voltage and a low-voltage side:
everything that carries or switches pack power (blocks 1–5 in the
[Schematic](#schematic) table) is on the **bottom**, the MCU and the
user interface (blocks 6–7) on the **top**.
- **Left end**: J3 (BAT) and J2 (OUT) wire pads, + and − of each pair
  3.5mm apart, wires entering from the left. The end is cut into **two
  symmetric tabs**, one per pair (mirror images about the board's
  centreline), as on the Jeti SPS-20: straight edges, 1mm corner radii,
  and each tab runs past its pads as bare board (no pour on either
  layer). Each pair gets its own heat shrink over tab, solder joints and
  wire insulation, so the shrink grips the board and the insulation, not
  the joints. "BAT"/"OUT" and "+"/"−" are on the top silkscreen.
- **Middle**: the BT832 at its native orientation, antenna over a
  **15 × 6.3mm notch** in the top edge (no board or copper under the
  antenna, as Fanstel recommends). Its left pin column (crystal, ADC, LED
  drive) faces the power end, the right column (debug, button, VDD) faces
  J1/J4.
- **Top side** (what you see, touch or plug in): U1; Y1 with C1/C2 in a
  column beside U1's crystal pins; the LED driver (Q5/Q6 with R13–R15)
  between the wire tabs and U1; LED1 and SW1 below the module; at the
  right end J1 (SWD header, top-right corner) and J4 (right-angle GH,
  cable entry flush with the right edge), with C5, C6 (VDD decoupling),
  R4 (reset pull-up) and R16 (button) in one row between them. **J1 stays
  on the top** (needed for the debug cable with the board in its case).
- **Bottom side** (power), left to right: Q4 with D1/R1 behind the BAT
  tab (reverse polarity), Q3 with R9/R10/C7/D2 behind the OUT tab (load
  switch), R11 in the corner below Q3; the switch-off chain (Q1, R5, R6,
  Q2, R7, R8) and the ADC divider bottom (R12/C8) under the module; the
  regulator chain R2/C3 → U2 (R3) → L1/C4 under J4. The board goes into a
  **3D-printed case**, so tall SMD parts on the bottom are fine; what
  must not stick out are through-hole leads: J2/J3 wires and LED1's leads
  are **trimmed flush** after soldering.
- **Silkscreen**: reference designators horizontal, right beside their
  part (left of it or above it where there's room), **0.85mm text /
  0.15mm stroke** throughout, rows of parts with their labels on one line.
  BAT/OUT 1.0mm, +/− 1.2mm. Values are on the fab layer only. Silk lines
  are clipped ≥0.15mm clear of pad mask openings and holes (so the
  footprints differ from the library: `lib_footprint_mismatch` is set to
  ignore in the project).

**Copper**:
- **Power path on the bottom as solid copper**: BATT+ pour (J3+ → Q4
  drain), the **VBAT bar** (pour joining Q4's and Q3's sources, ~7.9mm
  wide, with a no-tracks rule area across its middle so no other net cuts
  it in two), LOAD_OUT pour (Q3 drain → J2+).
- **GND**: pours on both layers, stitched. The **load return** (OUT− →
  BAT−) runs along the left end as a **top-side GND strap**: a no-tracks
  rule area (~6mm wide, past both − pads) filled by the F.Cu GND pour, so
  no signal can cut it. J2/J3's GND pads connect solid (no thermal
  relief), since they carry the load return. No GND pour around the + pads
  on the top (rule areas), so the + pad never sits next to GND copper.
- **No copper on top under the BT832 body** (rule area, tracks and pours):
  its unused LGA pads sit there and would only be separated from traces by
  solder mask.
- Only **45° corners** (no 90° bends).
- Net classes: Power 0.3mm (VBAT branches, BATT+, LOAD_OUT, GND traces),
  Reg 0.25mm (+3V3, regulator VIN, switch node; fits U2's 0.5mm pitch),
  Default 0.2mm; vias 0.6–0.7/0.3mm. Solder mask expansion 0.05mm
  (0.025mm on U2's 0.5mm-pitch pins, keeping 0.15mm webs). A custom rule
  (`heimdall-switch.kicad_dru`) allows neck-down to 0.15mm where traces
  enter fine-pitch pads (U1, U2), well inside JLCPCB's 0.127mm minimum.
- 40 vias in total, ~520mm of track (~215mm top, ~305mm bottom).
- **GND stitching**: 19 GND vias plus the 3 through-hole GND pads tie the
  two GND pours together. 8 of the vias (0.7/0.3mm) were added on
  2026-10-04 with `route_pcb.py gapstitch`, only where both pours are
  solid around the via and outside courtyards and keep-outs: every pour
  fragment big enough for a via now has at least 2 ties (one 5.8mm²
  bottom fragment has room for only 1), and of the ~151mm² where both
  layers have GND, 2% is more than 5mm from a tie (was 6%; worst point
  7.4mm, was 9.1mm). The regulator's and the BT832's GND pins have a tie
  within ~1mm. DRC unchanged afterwards (0 unconnected, no new
  violations). The layout pictures and 3D renders above predate these
  vias.

**Current capacity** (design target **5A continuous, 15A peaks <1s**).
Expected load, per servo: analog standard servos stall at ~0.8-1.2A
(4.8-6V); digital high-torque standard ~2.5-3.5A at 6V; HV high-torque
standard up to ~4-5A at 7.4-8.4V. Six digital servos all stalled at once
would be ~18-20A, which in practice doesn't happen; realistic peaks are
6-12A for 10-100ms when everything moves at once, with 2-5A continuous.
Short peaks barely heat copper; the continuous figure sets the width.
IPC-2221 (outer layer, 1oz/35µm, 20°C rise): 1.4mm for 3A, 2.5mm for 5A,
4.8mm for 10A. The power path's narrowest copper: BATT+ and LOAD_OUT
pours ~5.5mm, VBAT bar ~7.9mm, so roughly 10A continuous on 1oz; the GND
strap on top is ~6mm. Both − pads are plated through-holes, so the return
current changes layer in the pad barrels.
AO4407A: −12A continuous, −60A pulsed; at 10A its ~13mΩ is 1.3W, too
warm for SO-8 continuously, fine for the expected 2-5A (≤0.3W).
**2oz copper** (a JLCPCB option, extra cost) roughly doubles the copper
figures if long stalls are expected. **Decision: first iterations are
ordered with standard 1oz**; 2oz is an option for later boards. Before
switching, check JLCPCB's minimum trace/space for 2oz: heavier copper
usually raises it, and this layout has 0.15mm neck-downs at U1/U2's
pins and 0.2mm clearances, which may need widening. The wire pads take
0.75mm² (18AWG), good for ~10A in a harness.

**How it was made**: rev 2 was placed by script from the rev 1 board
(parts moved to their zones, power parts flipped to the bottom), the power
pours, rule areas and the critical runs (J1 ↔ U1 SWD fan-out, ADC lane,
VBAT/gate-drive runs) laid by hand-written scripts, the rest routed by
[Freerouting](https://github.com/freerouting/freerouting) 2.4, then
cleaned up (GND stitching, 90° corners turned into two 45° bends) and
finished by hand in the KiCad GUI. **The `.kicad_pcb` is the source of
truth**; `place_pcb.py`/`route_pcb.py` in `hardware/kicad/` are the rev 1
generators (coordinates of the earlier 63.5mm board) and don't produce
rev 2, so don't run them on it.

**Ordering (JLCPCB)**: `python jlc_export.py` (KiCad's python, from
`hardware/kicad/`) writes the whole order package to `gerber/`
(`python jlc_export.py ../kicad-ui` does the same for the UI board, into
`hardware/kicad-ui/gerber/`; see [Daughter board (UI)](#daughter-board-ui)):
- `heimdall-switch.zip`: Gerbers + Excellon drill (board plot settings:
  Protel extensions, mask subtracted from silk). Order options: 2 layers,
  1.6mm, **HASL with lead**, 1oz.
- BOM + CPL in JLC's format, three sets: both sides
  (`-BOM.csv`/`-CPL.csv`), **top only** (`-top`) and **bottom only**
  (`-bottom`), for one-sided "Economic" PCBA of either side if a batch is
  ever machine-assembled. The plan for now is bare boards and hand
  assembly; see [BOM](#bom).
- Parts without an LCSC number are left out (U1 BT832, J2/J3 wire pads):
  JLC can't place them, they're hand-soldered either way.
- **Rotation**: JLC reads bottom-side angles mirrored, so the script
  writes `180° − KiCad angle` for bottom parts (KiCad angle on top), plus
  a per-footprint correction (`ROT_OFFSET`) where JLC's 3D model doesn't
  share KiCad's zero angle (SOT-23 +180°, SOT-583-8 +270°). The
  corrections come from rev 1's placement preview, where D1/D2/U2/Q1/Q2
  sat on the bottom at 180°. **Check the placement preview every time**,
  and for rev 2 especially: **D1** (the first diode at 90° on the bottom;
  cathode band = pad 1 = the VBAT end, a reversed zener keeps Q4 off),
  D2, **Q3/Q4** (SO-8, on the bottom for the first time: pin 1 dot),
  U2, Q1/Q2.
- Position = centre of the part's pads (as JLC expects), Y negated.

**Check before ordering**:
- Simulation and copper checks: done, see
  [Verification](#verification-simulation-and-copper).
- BT832 footprint and pin map: verified against Fanstel's official KiCad
  library (see [Schematic](#schematic)). A 1:1 print with a real module on
  it is still a cheap final check if a module is at hand.
- Run JLC's DFM check on the rev 2 Gerbers (rev 1 was clean except the
  "THT to SMD" assembly rule, irrelevant for bare boards).
- Through-hole GND pads (J2/J3 pin 2, LED1 pin 1) connect solid to the
  pours (no thermal relief): use a hot iron.

## Verification (simulation and copper)

Pre-order checks of the power side, scripts in
[hardware/sim/](../hardware/sim/), run with KiCad's bundled python (it
ships ngspice): `python run_sims.py` (all circuit cases, ~10s) and
`python copper.py` (copper of the load path from the `.kicad_pcb`).
Results from 2026-10-04 on rev 2. **Nothing needed changing.**

**Circuit (ngspice)**: blocks 1–5 as in the schematic netlist (battery +
lead inductance, Q4/D1/R1, Q3 with C7/D2/R9‖R10, the Q1/Q2 OFF chain,
R2/C3 into the regulator, ADC divider, load). Every case runs on two
model sets that bracket the real part: MOSFET models fitted to the
datasheets (AO4407A 10.0/26.1mΩ at V_GS −10/−5V vs datasheet 10/27), and
AOS's own AO4407A model (downloaded by the script; 9.5/12.2mΩ at
−10/−6V vs 10/12.7). The fit has the lower threshold (earlier, slower
turn-on: pessimistic for Q3 stress), the AOS model the higher one.

| Check | Fitted models | AOS model | Verdict |
|---|---|---|---|
| Plug-in, full 3S, 0.3–2µH leads | VBAT peak 12.6V, U2 VIN 11.6V, Q3 stays off (V_GS ≈ 0) | same | No spike (R_IN, no low-ESR cap on VBAT) |
| Q3 starts conducting after power-up (C7 220nF) | 3S 40–70ms, 2S 61–114ms over V_th −1.7…−3.0V | 3S 92ms, 2S 153ms | ≥2× the 20ms firmware window; 100nF would fail it (19ms) |
| Q3 turn-on into 5A + 1000µF | 3S: 21W peak, ~21ms half-on; 2S: 11W, ~35ms | 3S: 24W, ~12ms; 2S: 12W, ~21ms | Within the AO4407A single-pulse rating (~35W at 30ms) with ~2× margin |
| Q3 turn-on into 10A + 1000µF (3S) | 34W, ~40ms | 37W, ~17ms | Fitted case exceeds the rating (~25W at 60ms); servos idle at power-up, so only matters if something draws heavy current within ~100ms of switching on |
| OFF at full current, VBAT kick from battery leads | 5A/1µH 13.8V, 10A/2µH 16.6V; off in ~38µs | 5A/1µH 16.6V, 10A/2µH 22.9V; off in ~28µs | Inside Q3/Q4/Q5 30V, Q2/Q6 50V; D1 clamps Q4's gate; U2 VIN stays 12.5V. Smallest margin on the board (22.9 vs 30V) |
| MCU dead (fail-on), 12.6 / 8.4 / 6.0V | Q3 V_GS −12.5/−8.3/−5.9V, R_DS 8/13/21mΩ | 9/10/12mΩ | Output fully ON |
| Pack current while OFF (excl. regulator) | 24µA at 12.6V, 16µA at 8.4V | same | Matches the power budget |
| Reversed 3S pack | VBAT/LOAD/U2 VIN 0V, 0µA | same | Nothing conducts |

Not covered: the TPS629206 itself (TI's model is encrypted, PSpice for TI
only), the BT832/RF, ESD.

**Copper of the load path** (`copper.py`): each section's copper (zone
fills, tracks, pads; 1oz, 0.49mΩ/□) rasterised at 0.1mm from the board
and solved for DC current flow between its entry and exit pads; the GND
return on both layers, coupled through vias and plated pad holes.

| Section | R | 5A | 10A |
|---|---|---|---|
| BATT+ (J3+ → Q4 drain), B.Cu | 0.30mΩ | 1.5mV, 7mW | 3mV, 30mW |
| VBAT bar (Q4 → Q3 sources), B.Cu | 1.13mΩ | 5.6mV, 28mW | 11mV, 113mW |
| LOAD_OUT (Q3 drain → J2+), B.Cu | 0.28mΩ | 1.4mV, 7mW | 3mV, 28mW |
| GND return (J2− → J3−), F+B | 1.86mΩ | 9.3mV, 46mW | 19mV, 186mW |
| **Total copper** | **3.6mΩ** | **18mV, 0.09W** | **36mV, 0.36W** |

99% of the path carries ≤1.5A per mm of width at 5A (≤2.9A/mm at 10A),
against IPC-2221's ~2A/mm for a 20°C rise on 1oz; the local peaks
(~4A/mm at 5A) sit at pad corners where current enters a pad. The FETs
dissipate more than the copper: Q3 and Q4 ~0.2W each at 5A, ~0.8W each at
10A (R_DS(on) ~8–13mΩ at full gate drive).

## Buck regulator (TPS629206) reference design

Output is **3.3V**, chosen over 3.0V specifically because it's directly
available as an internal VSET preset with zero feedback components (see
below) — 3.0V isn't a VSET option at all (the preset table jumps 2.5V →
3.8V), so it would force the classic 2-resistor external-divider mode
instead. 3.3V is comfortably within the BT832's 1.7-3.6V VDD range.

**Output voltage configuration** (confirmed against the actual datasheet
tables, Table 8-1 and Table 8-2 — cross-checked against a user-provided
screenshot of Table 8-1 after an initial OCR pass mismapped which resistor
values select which mode):
- **MODE/S-CONF pin**: 27.40kΩ to GND — selects VSET (internal divider)
  mode, "up to 2.5MHz" switching (auto-adjusted for actual VIN/VOUT),
  output discharge enabled, Auto PFM/PWM with AEE (best light-load
  efficiency, which matters here since the system is asleep almost all the
  time)
- **FB/VSET pin**: left open (no component) — Table 8-2 row 18 shows
  "249kΩ or larger, or open" both select the top VSET preset, 3.3V
- No R1/R2 feedback divider needed at all — simpler and cheaper than the
  classic external-divider mode this part also supports

**Output filter** (Table 9-3 / component selection sections):
- L1 = 2.2µH — **selected: Murata DFE252012PD-2R2M=P2** (LCSC C237482),
  from TI's tested-inductor list (datasheet Table 9-4): 1008 / 2.5×2.0×1.2mm,
  shielded, DCR 84mΩ, I_sat 2.8A (30% drop), rated 2.2A. Sizing: switch
  current limit I_LIM_HS 1.1-1.7A plus ~0.2A propagation overshoot at
  12.6V in (datasheet Eq. 2) ≈ 1.9A worst case — the inductor must not
  saturate even in overload/short. Normal operation peaks only ~0.6A
  (power-save pulses: T_ON ≈ 100ns × VIN/(VIN−VOUT), Eq. 5-6).
- Soft-start is **internal** (T_SS 600-700µs after a 1-1.8ms start-up
  delay) — no soft-start capacitor needed.
- C_out = 22µF ceramic, X7R/X5R, low ESR — **selected: Samsung
  CL21A226MAQNNNE** (22µF 25V X5R 0805, LCSC C45783); the 25V rating
  keeps DC-bias derating at 3.3V small. Ordered: **Murata
  GRM21BR61E226ME44L** (TME), the same 22µF 25V X5R 0805 spec; the
  Samsung part is end-of-life at Mouser and out of stock at TME.
- C_in: TI's reference is 4.7µF 25V 1206. **Selected: Samsung
  CL31B106KBHNNNE, 10µF 50V X7R 1206** (LCSC C89632): same
  footprint, and at 12.6V it keeps roughly 5-6µF effective, where a
  4.7µF 25V part drops to ~2µF. The 50V rating also gives headroom for
  hot-plug ringing (below). Ordered: **Samsung CL31A106KBHNNNE** (TME),
  the same 10µF 50V 1206 in X5R (−55…+85°C instead of X7R's +125°C);
  no 10µF 50V 1206 X7R was in stock at TME or Mouser. Its DC-bias
  derating at 12.6V hasn't been checked against the X7R's 5-6µF figure.

**Hot-plug damping (R_IN, 22Ω 0603, LCSC C23345)**: plugging a pack into a
board whose input is only ceramic capacitance rings. The battery leads'
inductance and the near-zero-ESR ceramic form an undamped LC circuit, and
the first peak approaches **2× the pack voltage** (~25V on 3S; connector
bounce can repeat it). The TPS629206 is rated for 17V in. The usual fix, a
bulk electrolytic (≈47µF 25V) whose ESR damps the ring, is bigger than
this board, so instead R_IN sits between VBAT and the regulator's input
node (C_IN + VIN/EN):
- Critical damping for this LC is ~0.4Ω; 22Ω is far past it, so C_IN
  charges with no overshoot, and plug-in inrush into C_IN is capped at
  ~0.6A. Ringing on VBAT itself (now only small capacitance) is filtered
  by R_IN·C_IN (τ ≈ 110µs) before it reaches the regulator.
- The regulator's own draw is tiny (µA asleep, a few mA peak during radio
  bursts at pack voltage), so R_IN drops ≤0.1V. Its switching pulses come
  from C_IN, downstream of R_IN.
- Converter input-filter stability: |Z_in| of the buck at these loads is
  ≥1kΩ (V_IN² / P_IN), orders of magnitude above R_IN.
- The rest of VBAT tolerates the ring: Q3/Q4 (AO4407A) and Q1/Q5
  (AO3400A, via 1MΩ) are 30V parts, Q2/Q6 (BSS84) 50V, Q3/Q4 gates are
  zener-clamped, and Q6's gate sits at V_GS ≈ 0 at plug-in (LED off).
  The load path through Q3 doesn't go through R_IN.
- Simulated (see [Verification](#verification-simulation-and-copper)):
  with R_IN in place there is **no overshoot at all** on plug-in — VBAT
  rises to exactly the pack voltage and U2 VIN to ~11.6V, for 0.3–2µH of
  lead inductance — because VBAT itself carries no low-ESR capacitance
  (C_IN sits behind R_IN). The ~2× ring above is what R_IN prevents.
- **Verify on the first boards**: scope VBAT and U2 VIN while plugging in
  a full 3S pack a few times.

**Superseded**: an earlier pass at this section spec'd the TPS62901 (same
family, VQFN-HR package) with a classic-mode R1/R2 divider (402k/100k for
3.0V, 453k/100k for 3.3V) computed from that part's equation. Kept here
for reference only in case the VSET-preset approach above doesn't pan out
during bring-up and a fallback to classic external-divider mode is needed
— the same R1/R2 math applies to the TPS629206 too (also VFB = 0.6V).

## Assembly

- **PCBs**: bare boards from JLCPCB, surface finish **HASL with lead**
  (pre-tinned with leaded solder, matches the hand-assembly solder).
- **Parts**: from **TME** (next-day delivery) and **Mouser** (the BT832
  has to come from Mouser anyway, and the order clears its free-shipping
  threshold), see [BOM](#bom). Every part also keeps an LCSC number,
  preferring JLCPCB "basic" parts where that doesn't compromise the
  design — keeps an LCSC order or JLCPCB assembly possible for a later
  batch.
- **Hand assembly**: hot-air station + Sn63/Pb37 leaded paste for SMD,
  soldering iron (60/40) for the BT832's castellated edges and connectors.
  **No 0402** — passives 0603, 0805 where voltage/capacitance needs it.
  No-lead packages (DFN, SOT-5X3) are fine with hot air.
- **Battery in (J3) / load out (J2): solder pads, not connectors.** Wire
  pigtails soldered to the board, with whatever plug the vehicle needs on
  the end (JR/Futaba, XT30, …) — the same approach as the Jeti SPS-20, and
  the most vibration-proof option (no board-mounted connector to rattle
  loose or lever the joints). Footprint: KiCad
  `heimdall-switch:SolderWire-0.75sqmm_1x02_P3.5mm_D1.25mm_OD2.3mm`
  (KiCad's `Connector_Wire` P4.8mm footprint with the pads moved to
  3.5mm, so a pair sits side by side under one heat shrink)
  — through-hole pads (1.6mm drill) for 0.75mm² (≈18 AWG) wire, which
  carries 3A continuous / 6-8A peaks comfortably and also accepts 20-22
  AWG. Strain relief is heat shrink: the slot between the battery and
  load pairs makes two 7.3mm-wide tabs reaching 4mm past the pads, and
  a piece of heat shrink (~9-10mm, adhesive-lined is best) over each tab,
  its two solder joints and the first few mm of insulation keeps flexing
  off the joints (SPS-20 style).
  This replaced the "Relief" footprint variant (wire looped through
  extra holes), which cost ~14mm of board length.
- **Clean the board** (IPA, brush) after assembly, especially around the
  switching stage. R_PD1/R_PD2 (2.2MΩ) and R_CLAMP_PU (1MΩ) set the
  fail-on margin at a few µA, and flux residue plus humidity (boat use)
  can create leakage paths in the MΩ range. Conformal coating after
  bring-up is worth considering for the same reason.

## BOM

Schematic references (the descriptive names used elsewhere on this page are
in brackets; see [Schematic](#schematic) for the mapping). The prototype
run is ordered from **TME and Mouser**; every part also keeps an LCSC
number as the alternative source. The schematic carries both: the ordered
part in hidden `Manufacturer` / `MPN` / `Supplier` / `Supplier PN` fields,
the LCSC part in the `LCSC` field (used by `jlc_export.py`, see
[PCB layout](#pcb-layout)). **†** = the ordered part differs from the LCSC
alternative (the original choice, out of stock or not carried at TME and
Mouser); see the notes below the tables. Side: **T** top, **B** bottom
(rev 2). "Basic" = the LCSC alternative is a JLCPCB basic part (only
matters if a batch is ever JLC-assembled). Stock and prices checked
**2026-10-04** through the TME and Mouser APIs.

**Order files**: `python order_export.py [main UI cables]` (from
`hardware/kicad/`, default 10 5 5) writes `hardware/order/tme-basket.csv`
("symbol;quantity" lines for TME's basket import from file) and
`hardware/order/tme-customer-symbols.csv` ("symbol;customer symbol" for
TME's customer-symbol panel, our designators as e.g. `HSW-R6/R7/R13/R15`,
`HSW-UI-` for the UI board; TME keeps one customer symbol per product
across orders, hence the project prefix) and
`hardware/order/mouser-bom.csv` (for Mouser's BOM tool) from the
schematics' supplier fields, times the board counts, plus the UI cable's
crimp parts. The committed files are the 10 / 5 / 5 run; all lines were
checked orderable and in stock on 2026-10-04.

**Supplier lookups** ([hardware/sourcing/](../hardware/sourcing/),
stdlib-only python):
- `check_order.py`: checks the order files against the live TME and
  Mouser APIs (orderable, minimum quantity, stock), prints each line's
  cost and the totals, and points out cheaper price breaks. Run it right
  before ordering.
- `compare.py [main UI cables]`: prices every BOM line at LCSC (the `LCSC`
  field), TME and Mouser (the `MPN` / `Supplier PN` fields), as in the
  supplier comparison below.
- `find_part.py "<part number or phrase>" [-q qty]`: searches TME and
  Mouser, for finding a substitute when a part runs out.
- `suppliers.py`: the API clients. TME uses API v2 (OAuth2; tokens made
  after 2026-05-14 only work with v2), Mouser the Search API (a *Search*
  key, not the Order key), LCSC the product data its web pages load (no
  key). Keys come from the environment (`TME_TOKEN`, `TME_APP_SECRET`,
  `MOUSER_API_KEY`) or from `~/.config/heimdall/api-keys.env`, **never
  from the repo**.

**Main board** (42 parts; U1, U2, L1, Y1 from Mouser, the rest from TME,
J2/J3 are wire pads):

| Ref | Value | Ordered part | Package | Side | Order from | LCSC alternative | Basic |
|---|---|---|---|---|---|---|---|
| U1 | BT832 (nRF52832) | Fanstel BT832 | 14 × 16mm module | T | Mouser 308-BT832 | — (not at LCSC) | |
| U2 | 3.3V buck | TI TPS629206DRLR | SOT-583-8 | B | Mouser 595-TPS629206DRLR | [C5219292](https://www.lcsc.com/product-detail/C5219292.html) | |
| L1 | 2.2µH | Murata DFE252012PD-2R2M=P2 | 1008 | B | Mouser 81-DFE252012PD2R2MP2 | [C237482](https://www.lcsc.com/product-detail/C237482.html) | |
| Y1 | 32.768kHz, CL 12.5pF | Epson FC-135 32.7680KA-A5 | 3215 | T | Mouser 732-532.7680KA-A5 | [C32346](https://www.lcsc.com/product-detail/C32346.html) (Q13FC13500004) | ✓ |
| Q1, Q5 | N-FET | AOS AO3400A | SOT-23 | B, T | TME AO3400A | [C20917](https://www.lcsc.com/product-detail/C20917.html) | ✓ |
| Q2, Q6 | P-FET | Nexperia BSS84AK,215 † | SOT-23 | B, T | TME BSS84AK.215 | [C493579](https://www.lcsc.com/product-detail/C493579.html) (BSS84,215) | |
| Q3, Q4 | P-FET | AOS AO4407A | SO-8 | B | TME AO4407A | [C16072](https://www.lcsc.com/product-detail/C16072.html) | |
| D1, D2 (D_Z2, D_Z) | 18V zener | DC Components MMSZ5248B † | SOD-123 | B | TME MMSZ5248B-DC | [C2127](https://www.lcsc.com/product-detail/C2127.html) (JSCJ MMSZ5248B) | |
| C1, C2 | 18pF 50V C0G | Samsung CL10C180JB8NNNC | 0603 | T | TME CL10C180JB8NNNC | [C1647](https://www.lcsc.com/product-detail/C1647.html) | ✓ |
| C3 (C_IN) | 10µF 50V X5R | Samsung CL31A106KBHNNNE † | 1206 | B | TME CL31A106KBHNNNE | [C89632](https://www.lcsc.com/product-detail/C89632.html) (CL31B106KBHNNNE, X7R) | |
| C4 (C_OUT) | 22µF 25V X5R | Murata GRM21BR61E226ME44L † | 0805 | B | TME GRM21BR61E226ME44L | [C45783](https://www.lcsc.com/product-detail/C45783.html) (Samsung CL21A226MAQNNNE) | ✓ |
| C5 (C_VDD1) | 4.7µF 16V X5R | Samsung CL10A475KO8NNNC | 0603 | T | TME CL10A475KO8NNNC | [C19666](https://www.lcsc.com/product-detail/C19666.html) | ✓ |
| C6, C8 (C_VDD2, C_FB) | 100nF 50V X7R | Yageo CC0603KRX7R9BB104 | 0603 | T, B | TME CC0603KRX7R9BB104 | [C14663](https://www.lcsc.com/product-detail/C14663.html) | ✓ |
| C7 (C_SS) | 220nF 50V X7R | Samsung CL21B224KBFNNNE | 0805 | B | TME CL21B224KBFNNNE | [C5378](https://www.lcsc.com/product-detail/C5378.html) | ✓ |
| R1, R11 (R_REV, R_FB_TOP) | 100kΩ | Yageo RC0603FR-07100KL † | 0603 | B | TME RC0603FR-07100K | [C25803](https://www.lcsc.com/product-detail/C25803.html) | ✓ |
| R2 (R_IN) | 22Ω | Yageo RC0603FR-0722RL † | 0603 | B | TME RC0603FR-0722RL | [C23345](https://www.lcsc.com/product-detail/C23345.html) | ✓ |
| R3 (R_MODE) | 27.4kΩ | Yageo RC0603FR-0727K4L † | 0603 | B | TME RC0603FR-0727K4L | [C22964](https://www.lcsc.com/product-detail/C22964.html) | |
| R4 (R_RST) | 10kΩ | Yageo RC0603FR-0710KL | 0603 | T | TME RC0603FR-0710K | [C98220](https://www.lcsc.com/product-detail/C98220.html) | ✓ |
| R5, R8 (R_G1, R_LIM) | 100Ω | Yageo RC0603FR-07100RL † | 0603 | B | TME RC0603FR-07100R | [C22775](https://www.lcsc.com/product-detail/C22775.html) | ✓ |
| R6, R7, R13, R15 (R_OFF_PD, R_CLAMP_PU, R_Q6_PU, R_LED_PD) | 1MΩ | Yageo RC0603FR-071ML † | 0603 | B, B, T, T | TME RC0603FR-071M | [C22935](https://www.lcsc.com/product-detail/C22935.html) | ✓ |
| R9, R10 (R_PD1, R_PD2) | 2.2MΩ | Yageo RC0603FR-072M2L † | 0603 | B | TME RC0603FR-072M2 | [C22938](https://www.lcsc.com/product-detail/C22938.html) | |
| R12 (R_FB_BOT) | 33kΩ | Yageo RC0603FR-0733KL † | 0603 | B | TME RC0603FR-0733KL | [C4216](https://www.lcsc.com/product-detail/C4216.html) | ✓ |
| R14 (R_LED) | 680Ω 1/4W | Yageo RC1206FR-07680RL † | 1206 | T | TME RC1206FR-07680R | [C17975](https://www.lcsc.com/product-detail/C17975.html) | |
| R16 (R_BTN) | 1kΩ | Yageo RC0603FR-071KL † | 0603 | T | TME RC0603FR-071K | [C21190](https://www.lcsc.com/product-detail/C21190.html) | ✓ |
| LED1 | green 525nm, 8-14cd, 30° | Kingbright L-7104ZGCK † | 3mm THT, water clear | T | TME L-7104ZGCK | [C414645](https://www.lcsc.com/product-detail/C414645.html) (Everlight 204-10SUGC/S400-A4) | |
| SW1 | tactile | C&K PTS810 SJM 250 SMTR LFS | 4.2 × 3.2mm SMD | T | TME PTS810SJM250SMTRLF | [C116501](https://www.lcsc.com/product-detail/C116501.html) | |
| J1 | ARM 10-pin SWD | Connfly DS1031-08-2\*5P8BS41-3A † | 2×5 1.27mm SMD | T | TME ZL322-2X5P | [C41376037](https://www.lcsc.com/product-detail/C41376037.html) (hanxia HX PZ1.27-2x5P TP) | |
| J4 | UI breakout | JST SM03B-GHS-TB(LF)(SN) | GH 1×3 1.25mm SMD right-angle | T | TME SM03B-GHS-TB | [C514175](https://www.lcsc.com/product-detail/C514175.html) | |
| J2, J3 | wire pads | see [Assembly](#assembly) | THT pads | — | — | — | |

**UI daughter board** (see [Daughter board (UI)](#daughter-board-ui)), all from TME:

| Ref | Value | Ordered part | Package | Side | Order from | LCSC alternative |
|---|---|---|---|---|---|---|
| LED1 | green 3mm | Kingbright L-7104ZGCK † | 3mm THT | front | TME L-7104ZGCK | [C414645](https://www.lcsc.com/product-detail/C414645.html) (Everlight 204-10SUGC/S400-A4) |
| SW1 | tactile, IP67, 3.4N | C&K KSC641J LFS | 6.2 × 6.2mm SMD | front | TME KSC641JLFS | [C226344](https://www.lcsc.com/product-detail/C226344.html) |
| J1 | UI cable | JST SM03B-GHS-TB(LF)(SN) | GH 1×3 1.25mm SMD right-angle | back | TME SM03B-GHS-TB | [C514175](https://www.lcsc.com/product-detail/C514175.html) |

**UI cable** (J4 ↔ UI J1, pin 1 ↔ pin 1), per cable, from TME:

| Qty | Part | Order from | LCSC alternative |
|---|---|---|---|
| 2 | JST GHR-03V-S housing, GH 3-pin | TME GHR-03V-S | [C160417](https://www.lcsc.com/product-detail/C160417.html) (only 20 in stock on 2026-10-04) |
| 6 | JST SSHL-002T-P0.2 crimp contact, 26-30 AWG | TME SSHL-002T-P0.2 | [C189897](https://www.lcsc.com/product-detail/C189897.html) |
| 3 | 26-28 AWG wire, to length | — | — |

GH crimps need a fine crimp tool (or buy ready-made GH 3-pin
"pre-crimped" leads, often sold for drones/Pixhawk; check pin 1 ↔ pin 1).

Notes:
- **R3 (R_MODE) must be exactly 27.4kΩ (E96)**: it selects the TPS629206's
  mode by resistor window, so a 27kΩ E24 substitute is not safe.
- **U1: plain BT832, not BT832-P / newer nRF52832 revisions with locked
  APPROTECT**: those lock the debug port unless the firmware keeps it
  open (needs a recent SDK); the plain module is easier for prototypes.
  Fanstel's own store sells in 1000s; Mouser stocks single modules.
- **Substitutes (†)** for the TME order, checked against the design:
  - Resistors: Yageo RC series, same values, 1% (R2 was 5%). TME sells
    the UNI-ROYAL parts only in 5000-piece reels.
  - Q2/Q6 BSS84AK: see [Switching stage](#switching-stage), the threshold
    is higher than the BSS84's (good for fail-on), the I_DSS spec looser.
  - C3 X5R instead of X7R, C4 Murata instead of Samsung: see
    [Buck regulator](#buck-regulator-tps629206-reference-design).
  - D1/D2: same MMSZ5248B from another maker (DC Components).
  - J1 Connfly: land pattern checked against the stock footprint, see
    [Pin assignment](#pin-assignment-bt832-castellated-edge).
  - LED1 Kingbright: see below.
- **LED1: 3mm green, high intensity, narrow beam** for sunlight
  visibility through a 3mm hole in the hull (see Status LED above for the
  VBAT drive and currents). Ordered: **Kingbright L-7104ZGCK** (InGaN,
  water clear, 525nm, 8cd min / 14cd typ at 20mA, 30°, V_F 3.3V typ at
  20mA, 25mA max). The original choice, Everlight 204-10SUGC/S400-A4
  (3.2cd, 20°), was out of stock at TME and Mouser on 2026-10-04; it
  stays the LCSC alternative. It was chosen over Hubei KENTO 3AG2HD
  (C2843819, 2-3cd, 23°) for the higher intensity and Everlight datasheet
  quality. The LED only blinks on events, so its current doesn't show in
  the power budget.
- **SW1 (main board)**: C&K PTS810 SJM 250 SMTR LFS, 4.2 × 3.2mm
  J-lead tactile (KiCad `Button_Switch_SMD:SW_SPST_PTS810` matches
  exactly). The on-board button sits inside the hull, so it needn't be
  sealed, and the KSC641J's 6.2mm body was too big for the main board.
  Alps SKRPACE010 (C139797) is the same size/package if stock runs out
  (check its land pattern against the PTS810 footprint).
- **SW1 (daughter board)**: C&K KSC641J — IP67 sealed tactile switch,
  J-lead (easy to solder by hand), 3.4N actuation (firm enough to resist
  vibration presses), for the outside housing. KiCad's stock
  `Button_Switch_SMD:SW_Push_1P1T_NO_CK_KSC6xxJ` footprint matches it
  exactly.
- **J4 / UI J1**: the same JST GH 1.25mm right-angle header on both
  boards (cable plugs in from the side, along the board). The UI board
  had a vertical BM03B-GHS-TBT until 2026-10-04; side entry suits its
  housing better, and one part number covers both ends.

### Cost estimate (prototype run)

For **10 main boards + 5 UI boards + 5 cables**, prices 2026-10-04 from
the TME and Mouser APIs, in SEK excl. VAT (TME returns prices incl. 25%
VAT, converted here; Mouser's API prices are taken as excl. VAT, not
verified). Quantities are bought per piece at TME, so there's little
over-buying.

| Item | Where | Order | ≈ SEK |
|---|---|---|---|
| BT832 × 10 | Mouser | 72.64 SEK each | 726 |
| U2, L1, Y1 × 10 | Mouser | 85 + 34 + 39 | 158 |
| **Mouser order** | | above Mouser's 800 SEK free-shipping threshold (not re-checked; confirm in the cart) | **885** |
| Main-board parts × 10 (rest of the BOM) | TME | | 360 |
| UI-board parts × 5 | TME | | 60 |
| Cable parts × 5 | TME | | 15 |
| **TME order** | | shipping not known yet; check at checkout | **435** |
| Main PCB × 10 (45.5 × 23mm, 2L, 1.6mm, leaded HASL) | JLCPCB | estimate, get a quote | ~50–100 |
| UI PCB × 5 (35 × 13mm, 2L, **2.0mm**) | JLCPCB | estimate, get a quote (2.0mm adds cost) | ~50–100 |
| Shipping JLCPCB | | estimate | ~100–200 |
| **Total** | | plus TME shipping | **~1520–1720** |

Per finished main board that's about **125 SEK in parts**, 73 of it the
BT832. For comparison, a Jeti SPS-20 is around $60.

Alternatives priced the same day (parts only, excl. shipping):
**LCSC + Mouser** (BT832, J4 and U2 from Mouser, the rest from LCSC with
no substitutes) came to ~1250 SEK, about 70 SEK less, but LCSC sells
passives in strips of 50-100 and ships from China. Neither TME nor Mouser
alone covers the BOM: TME has no BT832 or TPS629206, Mouser no AOS
MOSFETs and no stock of C3, C4, LED1 or the handful of equivalents
checked for them. Re-run the comparison with
`hardware/sourcing/compare.py` (see [BOM](#bom)).

## Daughter board (UI)

Separate KiCad project in [hardware/kicad-ui/](../hardware/kicad-ui/)
(`heimdall-switch-ui.kicad_pro/.kicad_sch/.kicad_pcb`, rendered
[schematic](../hardware/kicad-ui/heimdall-switch-ui.svg),
[top](../hardware/kicad-ui/render-top.png) and
[bottom](../hardware/kicad-ui/render-bottom.png) views). Use it when the
LED and button need to sit away from the main board, e.g. in a housing
on the outside of the hull, as on the Jeti SPS-20.

| Front, angled | Back, angled |
|---|---|
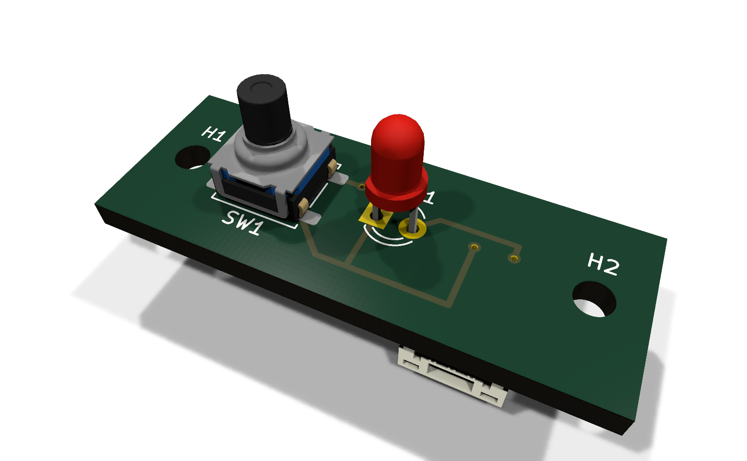
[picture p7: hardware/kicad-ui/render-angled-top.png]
UI board, front, angled
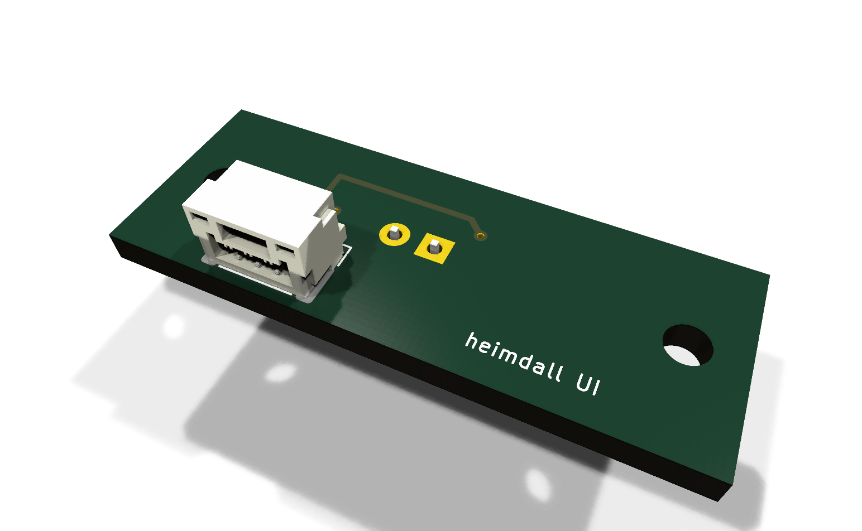
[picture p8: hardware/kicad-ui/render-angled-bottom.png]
UI board, back, angled
|  |  |

| Front | Back |
|---|---|
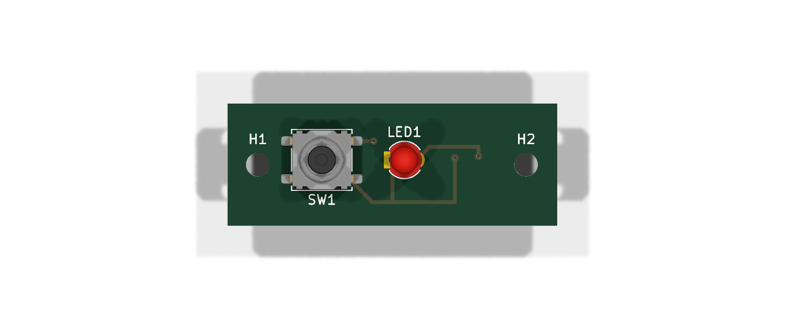
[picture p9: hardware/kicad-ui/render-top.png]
UI board, front
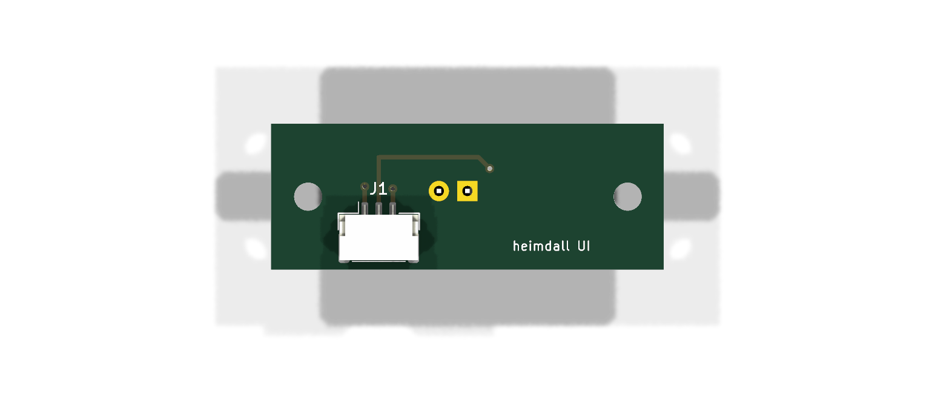
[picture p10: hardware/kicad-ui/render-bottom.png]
UI board, back
|  |  |

- **Parts**: LED1 (Kingbright L-7104ZGCK, 3mm green), SW1 (C&K KSC641J),
  J1 (JST SM03B-GHS-TB, right-angle SMD GH, the same part as the main
  board's J4), H1/H2 (tapped M3 holes, not parts). LED and
  button are the same part numbers as the main board's on-board ones;
  nothing else, since the
  LED driver, current limit and button ESD resistor live on the main
  board.
- **Cable**: 3-wire JST-GH (GHR-03V-S housings, SSHL-002T-P0.2
  contacts, see [BOM](#bom)), crimped to length, pin 1 ↔ pin 1 (1 LED_A,
  2 BTN, 3 GND).
- **Board**: 35 × 13mm, **2.0mm FR4** (order option at JLCPCB; the main
  board stays 1.6mm), 2 layers, two **tapped M3 holes** (H1/H2): 2.5mm
  tap drill, 28.5mm apart on the board's centreline, H1 3.2mm from the
  left edge. The board itself is tapped M3 and the screws come in from
  the housing, so no head/washer/nut clearance is needed on the board,
  only ~2mm around the thread (project-local footprint
  `heimdall-switch-ui:MountingHole_2.5mm_M3_Tapped`). 2.0mm FR4 holds 4
  threads (0.5mm pitch; 1.6mm would give ~3) and is stiffer under button
  presses: fine for clamping a light board, don't over-tighten. Worn
  threads: drill to 3.2mm and use screw + nut. From H1:
  button centre +6.8mm, LED centre +15.6mm, all on the centreline. LED
  and button on the front, facing out; the GH header is mounted on the
  **back** (SMD, so nothing comes through to the front) as a
  **right-angle** header with its opening at the **bottom long edge**, so
  the cable plugs in from the side and runs along the back of the board
  (changed from a vertical BM03B-GHS-TBT on 2026-10-04, so both ends of
  the cable use the same header). J1's body sits ~21–29.5mm from the
  left edge, between the LED leads and H2's ~2mm keep-out, its front
  ~0.8mm in from the edge as on the main board. Its GND and LED_A reach
  the front layer through one via each; BTN runs on the back to the
  button's via. Back silk carries the board name; the cable is pin 1 ↔
  pin 1.
- **Mounting**: in a 3D-printed housing screwed to the **outside** of the
  hull (like the SPS-20's), the LED protruding through the housing and
  the button sealed with an O-ring, so the only hull penetration is the
  cable hole. The KSC641J is IP67 itself, so a leaking O-ring doesn't
  kill the button.
- Verified (after the J1 change, 2026-10-04): ERC 0/0; DRC 0
  violations, 0 unconnected, full schematic parity (`kicad-cli pcb drc
  --schematic-parity`). Renders above regenerated.
- **Ordering**: `python jlc_export.py ../kicad-ui` (from
  `hardware/kicad/`) writes `hardware/kicad-ui/gerber/`: Gerber + drill
  zip and BOM/CPL (all, `-top`, `-bottom`), same format as the main
  board. Select **2.0mm** thickness on the JLCPCB order form (the Gerbers
  don't carry it). If it's ever assembled: SW1 is SMD on the front, J1
  SMD on the back (two "Economic" sides), LED1 is through-hole (hand
  solder, or JLC's Standard PCBA); J1/SW1 have no rotation corrections
  yet, so check the placement preview.
- `gen_ui.sh` generated the first version (schematic + routed PCB, with
  KiCad's Python API flipping J1 to the back), with the XH header that
  has since been swapped for the GH; don't re-run it. As with the main
  board, the KiCad files are the source of truth.

## Open items

- Real hardware not yet built — wake interval, scan window length, and BLE
  advertising interval (see [protocol.md](protocol.md)) are all first
  estimates, not measured.
- **Component selection, annotation and footprints: done** (see
  [BOM](#bom) and [Schematic](#schematic)). **Main board rev 2 layout:
  done and reviewed** (see [PCB layout](#pcb-layout)). Before ordering:
  BT832 footprint print-out check, JLC DFM check on the rev 2 Gerbers,
  a JLCPCB quote (see [Cost estimate](#cost-estimate-prototype-run)).
- **Y1/C1/C2**: kept in the design; fitted or not is decided at
  assembly. Firmware supports both clock sources (see LFCLK note above).
- Power budget is estimated, not measured.

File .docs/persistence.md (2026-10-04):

# Persistence (flash)

What the node keeps across power loss, and how it stores it without wearing
out the nRF52832's internal flash. No external memory part — the internal
flash is plenty.

## What's persisted

- **Last accepted replay counter** — always required. If it resets to 0 on
  reboot, any previously sniffed command frame becomes valid again (see
  [protocol.md](protocol.md)).
- **Commanded output state (ON/OFF)** — required: the switching element is
  a MOSFET with no memory of its own (the Jeti SPS-20 approach; see
  [hardware.md](hardware.md)'s Switching stage). Firmware restores it on
  boot within ~20ms of power-up, before the hardware's slow turn-on lets
  the load switch start conducting.

Both are written **together, only when an accepted command changes the
state**. Repeats of the current state are never written: commands are
absolute state, so replaying a same-state frame is harmless, and any older
frame that *would* change state carries a counter below the last persisted
one. The counter therefore costs no extra flash writes.

## Flash constraints (nRF52832)

- Erase sets a whole 4 KB page to all 1s; a write can only clear bits
  (1→0). Endurance is **10,000 erase cycles per page** — writes into
  already-erased space don't count against it.
- The NVMC also limits how many times the same word / block may be written
  between erases (`n_WRITE`, `n_WRITE,BLOCK` in the Product Specification's
  NVMC chapter — verify exact values there). Writing each word exactly once
  stays within both, so no bit-by-bit tricks.
- Word write ≈ 40 µs. Page erase ≈ 85 ms and stalls the CPU — keep it out
  of the command path.

## Scheme: append-only log over two pages

Two dedicated, reserved flash pages, A and B, both erased at first boot.

- **Record** = 8 bytes (two words), appended to the next free slot:
  - word 0: replay counter (32-bit, so it also covers a future widened
    counter — see protocol.md open items)
  - word 1: `0xA5` marker | reserved | state byte | inverted state byte
- **Write order**: counter word first, marker word last. A record only
  counts as valid once its marker word is valid, so a power cut mid-write
  leaves at worst an ignored half-record.
- **Boot**: scan A and B for the last valid record → restore state and
  counter. No valid record (fresh device) → OFF, counter 0.
- **Rollover**: when the active page is full (512 records), continue in the
  other page — it's already erased, so no erase in the command path. Erase
  the full page afterwards, while idle (not during a scan window). The new
  page always has a valid record before the old one is erased, so a power
  cut during erase never loses state.
- **Write verify / wear-out fallback**: read back each record after
  writing. On mismatch, keep running with state + counter in RAM and set a
  "flash worn" flag reported in the ack. The switch never bricks — it only
  loses power-loss memory.

## Lifetime

Each page is erased once per 1024 records (512 in A + 512 in B), so:
10,000 × 1024 ≈ **10 million state changes** — ~270 years at 100 changes
a day. Erase happens once per 512 changes, never inline with a command.

## Implementation note

Zephyr/NCS NVS and nRF5 SDK FDS both provide append-only wear-levelled
storage with torn-write recovery and could replace the hand-rolled scheme.
The hand-rolled version is ~50 lines and fully deterministic; which to use
follows from the (still open) toolchain choice.

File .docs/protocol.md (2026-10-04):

# BLE protocol

Roles: `heimdall-module`'s ESP32-C3 is the advertiser/sender. The nRF52 node
is a **passive scanner** most of the time — it does not advertise except in
the brief reactive burst described below. This is deliberate: minimizing
radio-on time on the nRF52 side is the main lever for power budget, more so
than chip-level sleep current specifics.

**Pairing** (one-time, power not a concern): standard BLE bonding, exchanges
a shared key and locks in static MAC addresses on both sides.

**Runtime cycle**, per nRF52 wake (currently assuming ~2-3s wake interval —
not yet validated on real hardware):
1. Wake → open short RX scan window (~5-10ms assumed, needs validation
   against chosen advertising interval)
2. If no valid command heard → sleep
3. If valid command (matches paired address + key + unit ID + counter >
   last accepted, for replay protection) → drive the output ON or OFF per
   commanded absolute state (never toggle logic, always an absolute state
   command). If the state changed, persist state + counter to flash
   ([persistence.md](persistence.md)) — the last accepted counter must
   survive reboot or old sniffed frames become valid again.
4. Advertise a short ack burst (a few adverts, ~100-300ms)
5. Sleep

**Command frame** (packed 32-bit value, module → switch node):

| Bits | Field |
|---|---|
| 31:24 | Unit ID |
| 23:16 | Rolling counter (replay protection) |
| 15:8 | Key check byte |
| 1 | State (1=ON, 0=OFF) |
| 0 | Reserved |

**Ack frame** (switch node → module → S.Port telemetry → transmitter Lua
widget):

| Bits | Field |
|---|---|
| 31:24 | Unit ID (echo) |
| 23:16 | Counter (echo) |
| 8 | Valid flag (command checked out AND output-sense ADC confirms power state) |
| 0 | New state |

Multi-unit safety: each node only reacts to its own paired address + unit
ID, so overlapping BLE range between multiple vehicles/units is a
non-issue by design.

## Open items

- **8-bit key check byte is forgeable**: an attacker can spray frames with
  random key bytes and a high counter and get ~1 in 256 accepted — no
  sniffing needed. Proposed fix: replace it with a truncated AES-CMAC/CCM
  MAC (4-8 bytes) over `{unit ID, counter, state}` using the pairing key
  (nRF52832 has hardware AES). Frame grows to ~12-16 bytes, still fits a
  legacy advert. Asymmetric signatures were considered and rejected: they
  don't prevent replay on their own (a counter is still needed), don't fit
  a legacy advert (64-byte Ed25519 signature), and have no hardware
  acceleration on the nRF52832.
- **8-bit counter wraps after 256 commands**: a plain `counter > last`
  check stops accepting at wrap. Widen to 32 bits (preferred, pairs with
  the MAC change) or use serial-number arithmetic.

## Transmitter-side Lua widget

Runs on the GX15 (EdgeTX), in the `heimdall-module` side of the system, not
in this repo. Sends the command via `sportTelemetryPush` when triggered,
shows a countdown, then reads the ack telemetry sensor to display "Hello"
(switched ON) / "Goodbye" (switched OFF) / "No response" based on the ack
frame's bits.

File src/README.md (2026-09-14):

# src/

Firmware source will live here once the nRF52 toolchain (nRF5 SDK vs. nRF
Connect SDK/Zephyr vs. upstream Zephyr) is chosen — see the repo root
README's Status section. Empty placeholder until then.

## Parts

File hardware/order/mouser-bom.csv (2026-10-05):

Mouser No | Mfr No | Manufacturer | Quantity | Refs
81-DFE252012PD2R2MP2 | DFE252012PD-2R2M=P2 | Murata | 10 | main: L1
308-BT832 | BT832 | Fanstel | 10 | main: U1
595-TPS629206DRLR | TPS629206DRLR | Texas Instruments | 10 | main: U2
732-532.7680KA-A5 | FC-135 32.7680KA-A5 | Epson | 10 | main: Y1

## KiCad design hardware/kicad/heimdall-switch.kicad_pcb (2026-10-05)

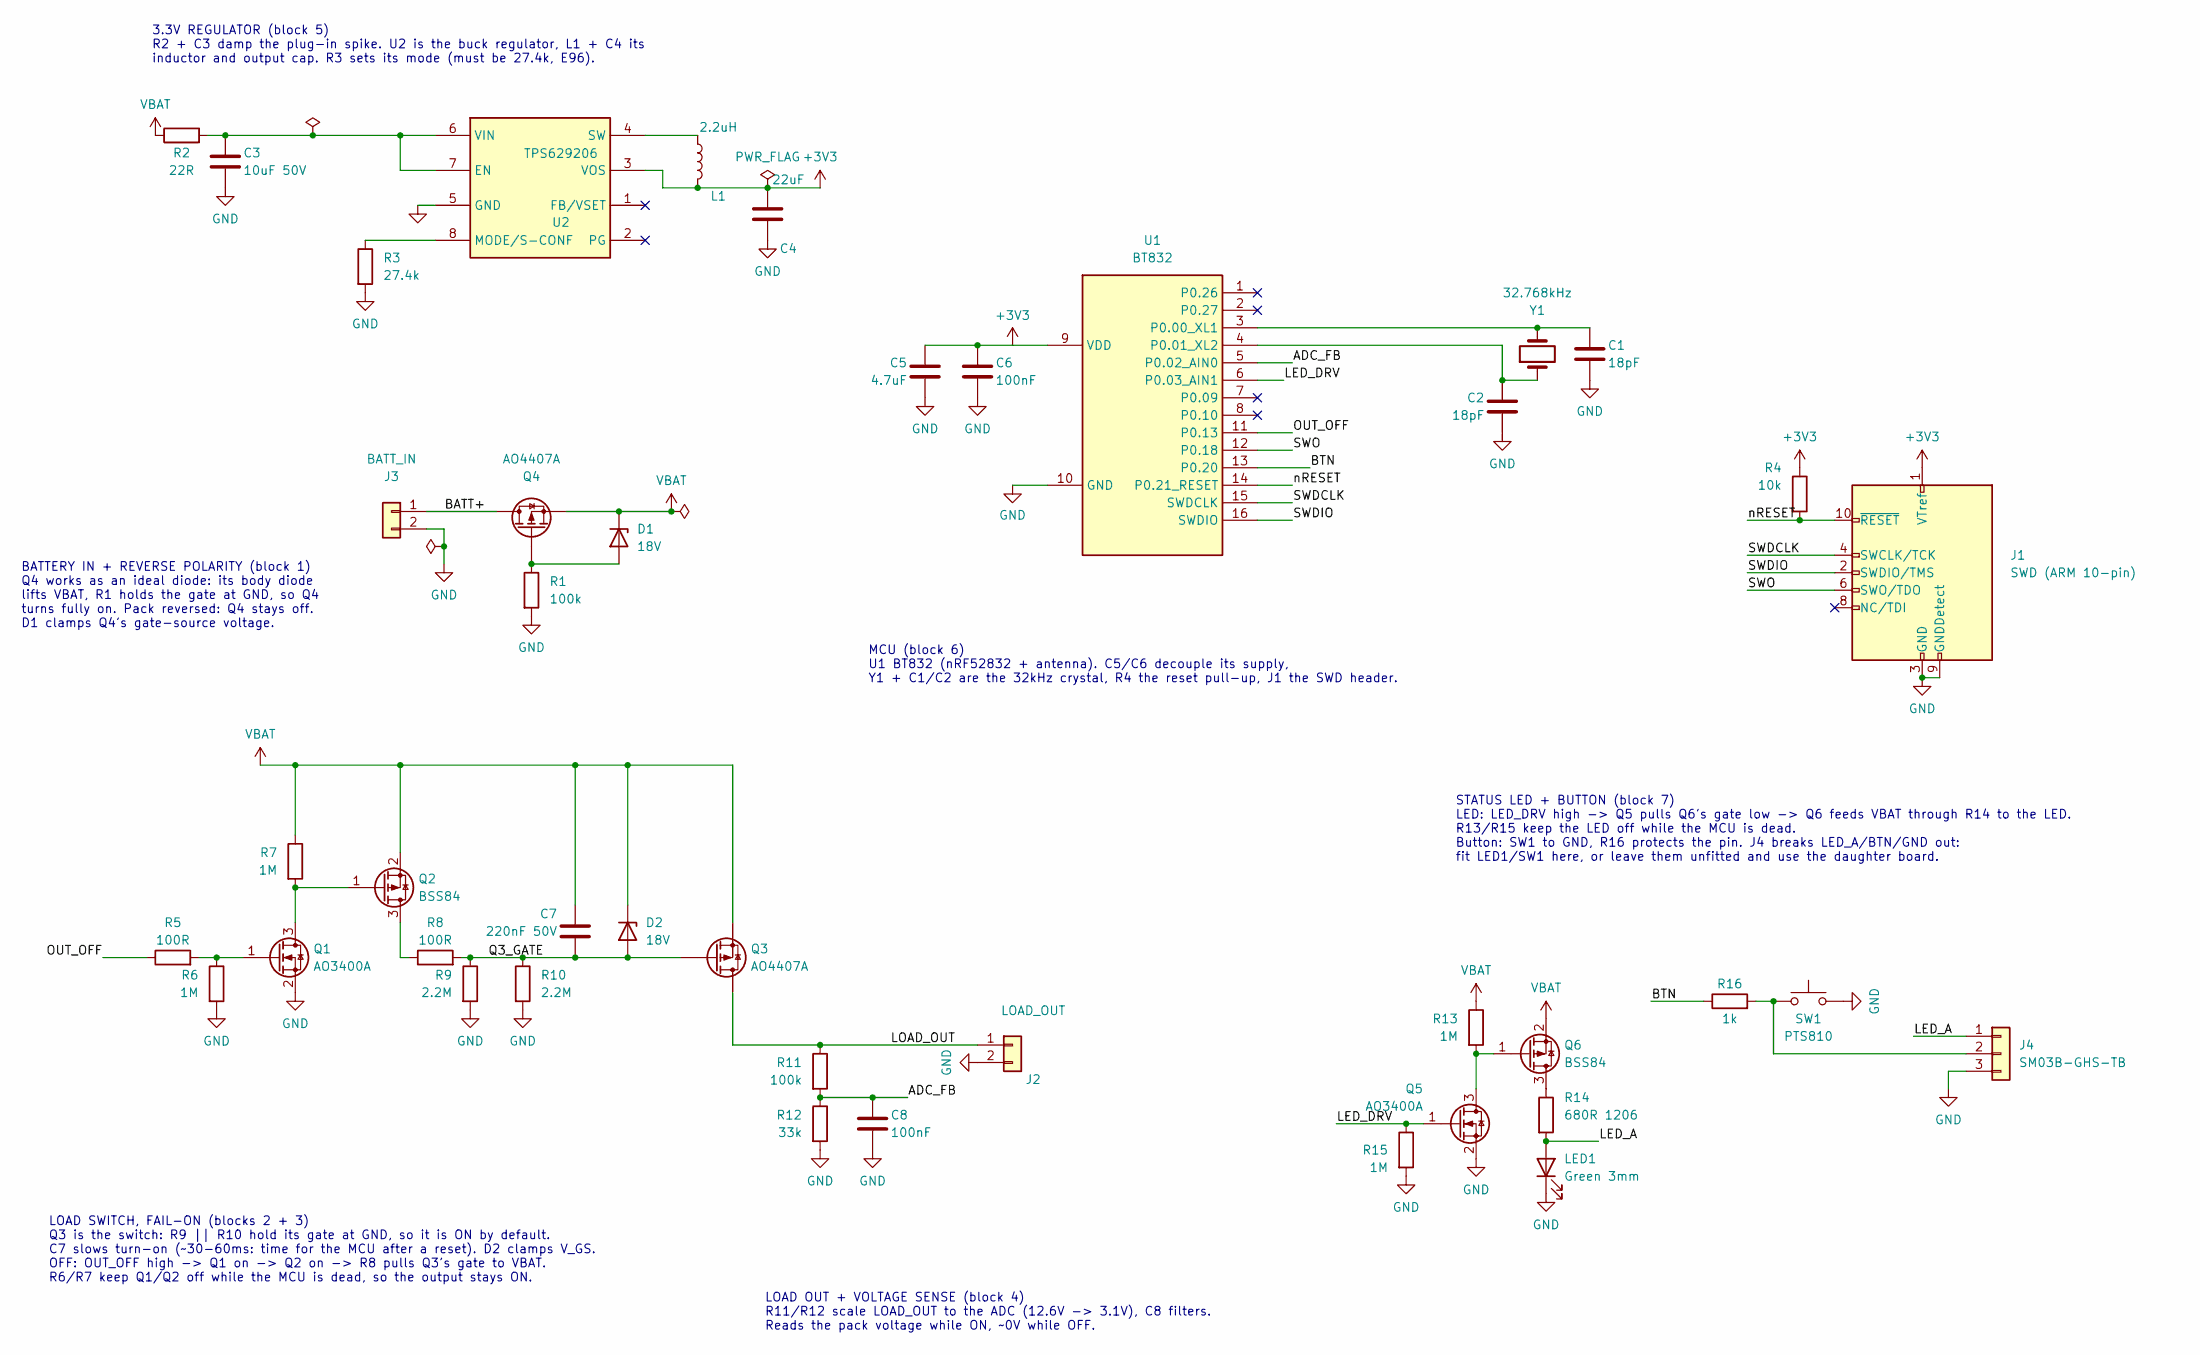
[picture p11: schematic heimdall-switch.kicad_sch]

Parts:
C1, C2: 18pF; C_0603_1608Metric; MPN CL10C180JB8NNNC; LCSC C1647
C3: 10uF 50V; C_1206_3216Metric; MPN CL31A106KBHNNNE; LCSC C89632
C4: 22uF; C_0805_2012Metric; MPN GRM21BR61E226ME44L; LCSC C45783
C5: 4.7uF; C_0603_1608Metric; MPN CL10A475KO8NNNC; LCSC C19666
C6, C8: 100nF; C_0603_1608Metric; MPN CC0603KRX7R9BB104; LCSC C14663
C7: 220nF 50V; C_0805_2012Metric; MPN CL21B224KBFNNNE; LCSC C5378
D1, D2: 18V; D_SOD-123; MPN MMSZ5248B; LCSC C2127
J1: SWD (ARM 10-pin); PinHeader_2x05_P1.27mm_Vertical_SMD; MPN DS1031-08-2*5P8BS41-3A; LCSC C41376037
J2: LOAD_OUT; SolderWire-0.75sqmm_1x02_P3.5mm_D1.25mm_OD2.3mm
J3: BATT_IN; SolderWire-0.75sqmm_1x02_P3.5mm_D1.25mm_OD2.3mm
J4: SM03B-GHS-TB; JST_GH_SM03B-GHS-TB_1x03-1MP_P1.25mm_Horizontal; MPN SM03B-GHS-TB(LF)(SN); LCSC C514175
L1: 2.2uH; L_1008_2520Metric; MPN DFE252012PD-2R2M=P2; LCSC C237482
LED1: Green 3mm; LED_D3.0mm; MPN L-7104ZGCK; LCSC C414645
Q1, Q5: AO3400A; SOT-23; MPN AO3400A; LCSC C20917
Q2, Q6: BSS84; SOT-23; MPN BSS84AK,215; LCSC C493579
Q3, Q4: AO4407A; SOIC-8_3.9x4.9mm_P1.27mm; MPN AO4407A; LCSC C16072
R1, R11: 100k; R_0603_1608Metric; MPN RC0603FR-07100KL; LCSC C25803
R2: 22R; R_0603_1608Metric; MPN RC0603FR-0722RL; LCSC C23345
R3: 27.4k; R_0603_1608Metric; MPN RC0603FR-0727K4L; LCSC C22964
R4: 10k; R_0603_1608Metric; MPN RC0603FR-0710KL; LCSC C98220
R5, R8: 100R; R_0603_1608Metric; MPN RC0603FR-07100RL; LCSC C22775
R6, R7, R13, R15: 1M; R_0603_1608Metric; MPN RC0603FR-071ML; LCSC C22935
R9, R10: 2.2M; R_0603_1608Metric; MPN RC0603FR-072M2L; LCSC C22938
R12: 33k; R_0603_1608Metric; MPN RC0603FR-0733KL; LCSC C4216
R14: 680R 1206; R_1206_3216Metric; MPN RC1206FR-07680RL; LCSC C17975
R16: 1k; R_0603_1608Metric; MPN RC0603FR-071KL; LCSC C21190
SW1: PTS810; SW_SPST_PTS810; MPN PTS810 SJM 250 SMTR LFS; LCSC C116501
U1: BT832; Fanstel_BT832; MPN BT832
U2: TPS629206; SOT-583-8; MPN TPS629206DRLR; LCSC C5219292
Y1: 32.768kHz; Crystal_SMD_3215-2Pin_3.2x1.5mm; MPN FC-135 32.7680KA-A5; LCSC C32346

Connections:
+3V3: C4.1, C5.1, C6.1, J1.1 (VTref), L1.2, R4.1, U1.9 (VDD), U2.3 (VOS)
/ADC_FB: C8.1, R11.2, R12.1, U1.5 (P0.02_AIN0)
/BATT+: J3.1, Q4.5 (D), Q4.6 (D), Q4.7 (D), Q4.8 (D)
/BTN: R16.1, U1.13 (P0.20)
/LED_A: J4.1, LED1.2 (A), R14.2
/LED_DRV: Q5.1 (G), R15.1, U1.6 (P0.03_AIN1)
/LOAD_OUT: J2.1, Q3.5 (D), Q3.6 (D), Q3.7 (D), Q3.8 (D), R11.1
/OUT_OFF: R5.1, U1.11 (P0.13)
/Q3_GATE: C7.2, D2.2 (A), Q3.4 (G), R8.2, R9.1, R10.1
/SWDCLK: J1.4 (SWCLK/TCK), U1.15 (SWDCLK)
/SWDIO: J1.2 (SWDIO/TMS), U1.16 (SWDIO)
/SWO: J1.6 (SWO/TDO), U1.12 (P0.18)
/nRESET: J1.10 (~RESET), R4.2, U1.14 (P0.21_RESET)
GND: C1.2, C2.2, C3.2, C4.2, C5.2, C6.2, C8.2, J1.3 (GND), J1.5 (GND), J1.9 (GNDDetect), J2.2, J3.2, J4.3, LED1.1 (K), Q1.2 (S), Q5.2 (S), R1.2, R3.2, R6.2, R9.2, R10.2, R12.2, R15.2, SW1.2, U1.10 (GND), U2.5 (GND)
unnamed: D1.2 (A), Q4.4 (G), R1.1
unnamed: J4.2, R16.2, SW1.1
unnamed: Q1.3 (D), Q2.1 (G), R7.2
unnamed: Q1.1 (G), R5.2, R6.1
unnamed: Q2.3 (D), R8.1
unnamed: Q5.3 (D), Q6.1 (G), R13.2
unnamed: Q6.3 (D), R14.1
unnamed: C1.1, U1.3 (P0.00_XL1), Y1.2
unnamed: C2.1, U1.4 (P0.01_XL2), Y1.1
unnamed: C3.1, R2.2, U2.6 (VIN), U2.7 (EN)
unnamed: R3.1, U2.8 (MODE/S-CONF)
unnamed: L1.1, U2.4 (SW)
VBAT: C7.1, D1.1 (K), D2.1 (K), Q2.2 (S), Q3.1 (S), Q3.2 (S), Q3.3 (S), Q4.1 (S), Q4.2 (S), Q4.3 (S), Q6.2 (S), R2.1, R7.1, R13.1

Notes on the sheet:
3.3V REGULATOR (block 5) R2 + C3 damp the plug-in spike. U2 is the buck regulator, L1 + C4 its inductor and output cap. R3 sets its mode (must be 27.4k, E96).
BATTERY IN + REVERSE POLARITY (block 1) Q4 works as an ideal diode: its body diode lifts VBAT, R1 holds the gate at GND, so Q4 turns fully on. Pack reversed: Q4 stays off. D1 clamps Q4's gate-source voltage.
LOAD SWITCH, FAIL-ON (blocks 2 + 3) Q3 is the switch: R9 || R10 hold its gate at GND, so it is ON by default. C7 slows turn-on (~30-60ms: time for the MCU after a reset). D2 clamps V_GS. OFF: OUT_OFF high -> Q1 on -> Q2 on -> R8 pulls Q3's gate to VBAT. R6/R7 keep Q1/Q2 off while the MCU is dead, s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
LOAD OUT + VOLTAGE SENSE (block 4) R11/R12 scale LOAD_OUT to the ADC (12.6V -> 3.1V), C8 filters. Reads the pack voltage while ON, ~0V while OFF.
MCU (block 6) U1 BT832 (nRF52832 + antenna). C5/C6 decouple its supply, Y1 + C1/C2 are the 32kHz crystal, R4 the reset pull-up, J1 the SWD header.
STATUS LED + BUTTON (block 7) LED: LED_DRV high -> Q5 pulls Q6's gate low -> Q6 feeds VBAT through R14 to the LED. R13/R15 keep the LED off while the MCU is dead. Button: SW1 to GND, R16 protects the pin. J4 breaks LED_A/BTN/GND out: fit LED1/SW1 here, or leave them unfitted and use the daughter bo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

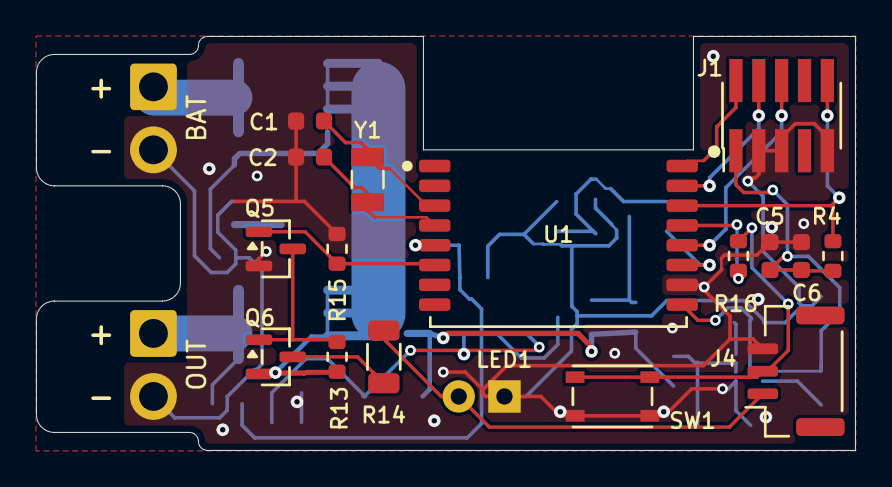
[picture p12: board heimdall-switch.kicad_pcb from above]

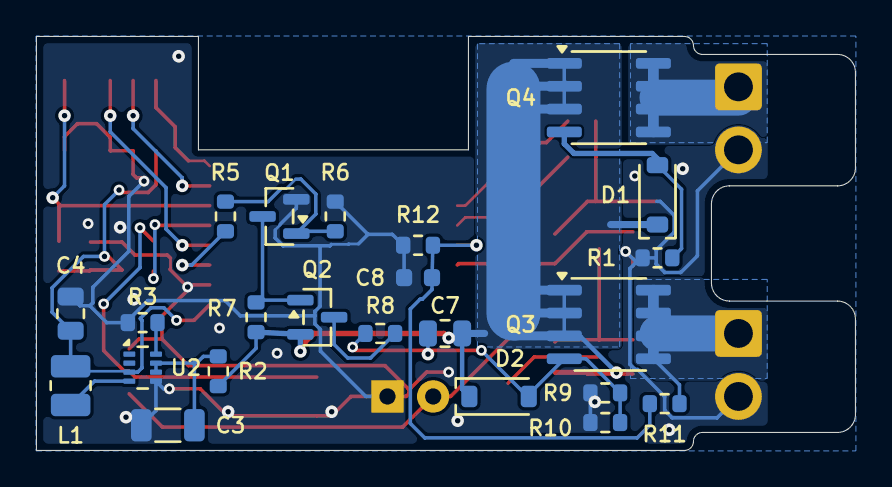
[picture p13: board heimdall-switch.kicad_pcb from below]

Board: 2 copper layers, 45.5 x 23.0 mm, 42 parts (23 on the bottom side), 27 nets.

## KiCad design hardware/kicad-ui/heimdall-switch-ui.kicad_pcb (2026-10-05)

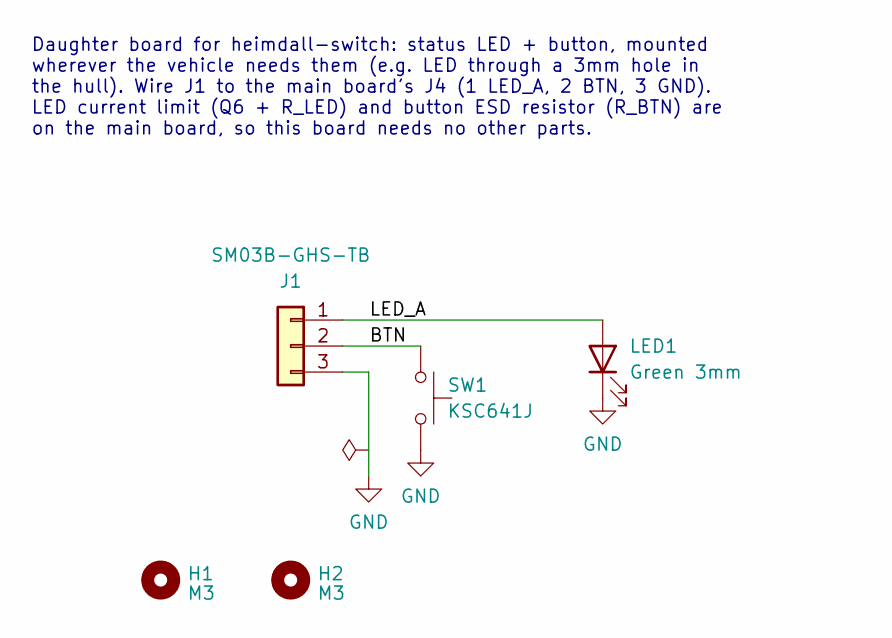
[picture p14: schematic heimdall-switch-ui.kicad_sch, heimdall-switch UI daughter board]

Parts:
H1, H2: M3; MountingHole_2.5mm_M3_Tapped
J1: SM03B-GHS-TB; JST_GH_SM03B-GHS-TB_1x03-1MP_P1.25mm_Horizontal; MPN SM03B-GHS-TB(LF)(SN); LCSC C514175
LED1: Green 3mm; LED_D3.0mm; MPN L-7104ZGCK; LCSC C414645
SW1: KSC641J; SW_Push_1P1T_NO_CK_KSC6xxJ; MPN KSC641J LFS; LCSC C226344

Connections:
/BTN: J1.2, SW1.1
/LED_A: J1.1, LED1.2 (A)
GND: J1.3, LED1.1 (K), SW1.2

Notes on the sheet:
Daughter board for heimdall-switch: status LED + button, mounted wherever the vehicle needs them (e.g. LED through a 3mm hole in the hull). Wire J1 to the main board's J4 (1 LED_A, 2 BTN, 3 GND). LED current limit (Q6 + R_LED) and button ESD resistor (R_BTN) are on the main board, so this board nee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

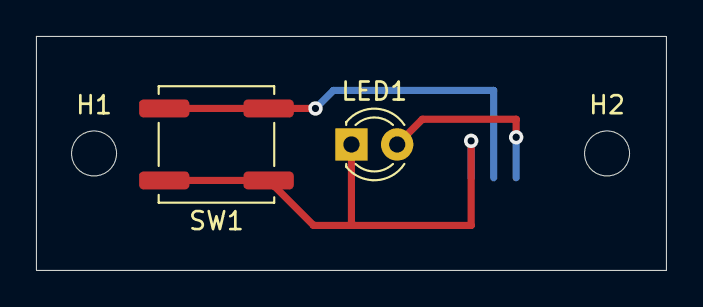
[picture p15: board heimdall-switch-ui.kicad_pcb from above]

Board: 2 copper layers, 35.0 x 13.0 mm, 5 parts (1 on the bottom side), 3 nets.

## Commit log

2026-09-14 Correct scope: generic RC switch, not boat-specific
    heimdall-switch is a general-purpose RC power switch node, not tied
    to boats -- the boat SPS-20 replacement was just the motivating use
    case. Renames the "Boat ID" protocol field to "Unit ID" and
    generalizes boat-only wording throughout. README also gets a
    mermaid diagram showing the EdgeTX Lua/OneClick -> heimdall-module ->
    heimdall-switch trigger flow.
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2026-09-14 Switch production MCU module from ISP1507 to Fanstel BT832
    The ISP1507's "hand/hot-air reworkable" claim was unverified and
    wrong -- it's a 62-pad bottom-only LGA (0.4mm pads, no side access),
    which needs stencil+paste reflow. Verified against the actual
    Fanstel BT832 datasheet (text-extracted via pdftotext) and the
    user-provided pinout diagram: its 16 castellated pins carry VDD,
    GND, SWDCLK/SWDIO/RESET, and 11 GPIOs (2 analog-capable), which
    covers every signal this design needs without touching the 24
    LGA-only pads. Fanstel's own datasheet states SMT equipment isn't
    required to solder the castellated pins.
2026-09-14 Add full BT832 pin assignment for schematic/PCB work
    Maps all 16 castellated pins: relay SET/RESET drive, ADC feedback,
    button, LED, programming header (VDD/GND/RESET/SWDCLK/SWDIO), and
    an LFCLK crystal on the shared XL1/XL2 pins for accurate wake/scan
    timing. Notes the NFCPINS UICR gotcha on P0.09/P0.10 and leaves 4
    GPIOs spare.
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2026-09-14 Note TPS62901 package as an accepted hot-air/reflow trade-off
    Only one package exists for this part (9-pin VQFN-HR, 0.5mm pitch).
    Recorded as a deliberate choice, not an oversight, since it's a
    tighter assembly bar than the BT832's hand-solderable edge.
2026-09-14 Switch regulator to TPS629206, use VSET preset for 3.3V
    Replaces TPS62901 (VQFN-HR, no-lead, reflow-only) with the
    TPS629206 -- same TPS6292xx family, identical 4uA IQ, but in a
    real gull-wing-leaded SOT-5X3 package confirmed from the datasheet
    package outline.
    Also switches from a classic R1/R2 feedback divider to the part's
    VSET internal-preset mode: MODE/S-CONF = 27.40k (VSET, Auto
    PFM/PWM+AEE) and FB/VSET left open selects the 3.3V preset
    directly, per Table 8-2. Picked 3.3V over 3.0V specifically because
    3.0V isn't a VSET preset (table jumps 2.5V to 3.8V) and would need
    the 2-resistor divider instead. Confirmed against a clean table
    screenshot after an initial OCR pass on the same tabl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
2026-09-14 Add first-draft KiCad schematic for heimdall-switch
    Hand-authored a full schematic implementing everything documented
    in .docs/hardware.md: TPS629206 buck (VSET-preset 3.3V config),
    BT832 with the confirmed castellated pinout, 32.768kHz crystal,
    SWD header, LED, button, ADC feedback divider, and a dual-coil
    latching relay driving a P-channel high-side load switch (relay
    and MOSFET are generic placeholders pending part selection).
    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
    [heimdall-switch.kicad_sch]
2026-09-29 Replace latching relay with fail-on MOSFET switch; add flash persistence
    Switching: drop the latching relay (no coils/mechanical parts) in favour
    of a single high-side P-FET whose hardware default is ON — the MCU must
    actively hold the output OFF, so any control-side failure (dead MCU,
    reset, brownout, regulator, firmware hang) leaves the load powered.
    Slow gate turn-on bridges MCU boot; watchdog is mandatory.
    Adds a P-FET ideal-diode reverse polarity stage at the battery input,
    covering the node and the load.
    State now survives power loss via flash (Jeti SPS-20 approach):
    append-only two-page log of {counter, state} per state change, ~10M
    changes of endurance, no erase in the command pa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
    [heimdall-switch.kicad_sch]
2026-09-29 Select switching FETs, add R_LIM; document assembly approach
    - Q3/Q4: AOS AO4407A (SO-8, C16072). Not specified at -4.5V, but the gate
    always sees the full pack voltage (>=~5V on 2S), where it is <=17mOhm.
    AONR21357 (DFN 3x3) noted as the upgrade for a shrunk board.
    - Q1: AO3400A (C20917), logic-level for the 3.3V GPIO drive.
    - Q2: Nexperia BSS84 (C493579), high threshold + <=100nA leakage for
    fail-on margin; leakage chain analysed, bench check documented.
    - R_LIM 100R between Q2 drain and Q3 gate caps the C_SS discharge spike
    through Q2 at turn-off (~1A -> ~0.1A).
    - Assembly: bare JLCPCB boards with leaded HASL, LCSC parts, hand/hot-air
    assembly with Sn63/Pb37, no 0402.
    Co-Author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
    [heimdall-switch.kicad_sch]
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2026-09-30 Select remaining components; add UI breakout and BT832 decoupling
    - BOM section in hardware.md with LCSC numbers; hidden LCSC field on
    every schematic part for BOM export
    - D_Z/D_Z2 15V -> 18V MMSZ5248B (lower leakage at 12.6V)
    - C_SS 50V 0805, C_IN 10uF 50V 1206, C1/C2 18pF for the 12.5pF FC-135
    - BT832 VDD decoupling C_VDD1 4.7uF + C_VDD2 100nF
    - Status LED is now a 5mm THT high-intensity red; LED1/SW1 moved to
    their own block with J4 breakout (LED_A/BTN/GND) for a daughter
    board, plus R_BTN 1k series ESD protection on P0.20
    - Open items: hot-plug ringing on 3S, J1 footprint
    [heimdall-switch.kicad_sch]
2026-09-30 Status LED: 3mm high-intensity green driven from VBAT
    Sunlight visibility through a 3mm hull hole needs an InGaN LED (~3.2V
    forward), which the 3.3V rail can't drive. LED1 is now an Everlight
    204-10SUGC (3.2cd, 20deg, water clear) fed from VBAT through R_LED
    (680R 1206) and switched low-side by Q5 (AO3400A) on P0.26, with a 1M
    gate pull-down. R_LED sits ahead of J4 so a shorted daughter-board wire
    stays current-limited. J4 is now 4 pads: LED_A / LED_K / BTN / GND.
    [heimdall-switch.kicad_sch]
2026-09-30 Status LED: high-side switch so the daughter board needs 3 wires
    Q6 (BSS84) now switches VBAT into R_LED/LED1 from the high side, driven
    by Q5 (AO3400A) with R_Q6_PU 1M; the LED cathode goes straight to GND.
    J4 is back to 3 pads: LED_A / BTN / GND, the LED and button sharing
    the ground wire. R_LED stays ahead of J4, so a shorted daughter-board
    wire is still current-limited.
    [heimdall-switch.kicad_sch]
2026-09-30 Add R_IN hot-plug damping in front of the regulator
    Plugging a 3S pack into ceramic-only input capacitance rings up to ~2x
    pack voltage, past the TPS629206's 17V rating. A bulk electrolytic
    would be bigger than the board, so R_IN (22R 0603) now sits between
    VBAT and C_IN/U2: heavily overdamped, caps inrush at ~0.6A, and drops
    <=0.1V at the regulator's mA-level draw. The load path is unaffected.
    [heimdall-switch.kicad_sch]
2026-09-30 J1: standard ARM Cortex Debug 10-pin header, add SWO
    J1 is now the 2x5 1.27mm ARM debug connector (Samtec FTSH-105-01-L-DV-K,
    male on the board) so J-Link/ST-Link/CMSIS-DAP probes plug straight in.
    SWO wired to P0.18 (the nRF52832's fixed trace pin, previously spare).
    J1 and R_RST moved to their own block, linked to U1 by net labels.
    [heimdall-switch.kicad_sch]
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2026-10-01 Add UI daughter board project; JST-XH breakout, KSC641J switch
    New KiCad project hardware/kicad-ui/ for the optional LED + button
    daughter board: schematic and routed 26x13mm 2-layer PCB (ERC 0/0, DRC
    clean with schematic parity). LED and button on the front, JST-XH
    header on the back so the board sits flat against the hull.
    Main board: J4 is now a JST B3B-XH-A (crimped cable to the daughter
    board), SW1 is the C&K KSC641J (matches KiCad's KSC6xxJ footprint).
    [heimdall-switch-ui.kicad_pcb, heimdall-switch-ui.kicad_sch, heimdall-switch.kicad_sch]
2026-10-01 UI daughter board: add two M3 mounting holes
    Board grows to 39x13mm with M3 holes 32mm apart at the ends, for a
    3D-printed housing on the outside of the hull (LED through the
    housing, button sealed with an O-ring). ERC 0/0, DRC clean with
    schematic parity.
    [heimdall-switch-ui.kicad_pcb, heimdall-switch-ui.kicad_sch]
2026-10-01 UI daughter board: tapped M3 holes, board down to 35x13mm
    Holes are now 2.5mm M3 tap drill (screws thread into the board from
    the housing), so only thread clearance is needed instead of a
    head/washer keep-out. Project-local footprint
    MountingHole_2.5mm_M3_Tapped. Holes 28.5mm apart. ERC 0/0, DRC clean
    with schematic parity.
    [heimdall-switch-ui.kicad_pcb, heimdall-switch-ui.kicad_sch]
2026-10-01 UI daughter board: 2.0mm FR4 (4 M3 threads in the tapped holes)
    [heimdall-switch-ui.kicad_pcb]
2026-10-01 Annotate main schematic and assign all footprints
    - Descriptive references (R_PD1, C_SS, D_Z, ...) renamed to R1-R16,
    C3-C8, D1-D2; old names kept in a hidden "Function" field and mapped
    in hardware.md
    - Footprints on every part (KiCad stock, plus project-local
    Fanstel_BT832 drawn from the datasheet with an antenna keep-out)
    - Q3/Q4 use a new AO4407A symbol: generic P-FET drawing with SO-8 pin
    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
    [heimdall-switch.kicad_sch]
2026-10-01 Main PCB: placement iteration 1 (unrouted); LED drive to P0.03
    Long, slim 95.8 x 23 mm board: battery/load wire pads with strain relief
    at the left end, Q4/Q3 right behind them on a short VBAT bar, gate
    networks and regulator in the middle, BT832 at the right end with its
    antenna overhanging the edge. Generated with place_pcb.py (KiCad python)
    from the netlist; DRC: no courtyard overlaps, full schematic parity.
    LED_DRV moved from P0.26 (pin 1) to P0.03 (pin 6) so the module's top
    pin row exits left without crossing the crystal.
    [heimdall-switch.kicad_pcb, heimdall-switch.kicad_sch]
2026-10-01 Main PCB placement iteration 2: two-sided, 71.8 x 23 mm
    Small parts (regulator, gate networks, LED driver, decoupling, crystal
    load caps) on the bottom; wires, power FETs, BT832, crystal, headers,
    button and LED on top. No courtyard overlaps, full schematic parity.
    [heimdall-switch.kicad_pcb]
2026-10-01 Main board SW1: small C&K PTS810 (4.2x3.2mm), placed next to LED1
    The sealed KSC641J stays on the daughter board, which sits outside the
    hull; the on-board button is inside, so a small unsealed part is fine.
    [heimdall-switch.kicad_pcb, heimdall-switch.kicad_sch]
2026-10-01 Main PCB placement iteration 3: BT832 mid-board, 63.5 x 23 mm
    U1 at native orientation in the middle, antenna over a 15 x 6.3 mm
    notch cut into the top edge (no board or copper under it, per Fanstel).
    Left pin column (crystal, ADC, LED) faces the power/regulator half,
    right column (debug, button, VDD) faces J4. J1 on the back under the
    module body; SW1/LED1 in the strip below it. No courtyard overlaps,
    full schematic parity. placement-top/bottom.png show the ratsnest.
    [heimdall-switch.kicad_pcb]
2026-10-01 Main PCB: readable silkscreen, spread the bottom cluster
    - Every reference designator on silk at 0.8mm (JLCPCB minimum), placed
    next to its own part and clear of pads, holes, other labels and the
    board edge (silk_labels.py, scored so labels aren't ambiguous);
    values moved to the fab layer
    - Bottom left section re-gridded into five rows with label space;
    regulator chain R2/C3 -> U2 -> L1 -> C4 kept in one line
    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
    [heimdall-switch.kicad_pcb]
2026-10-01 Main PCB: first full routing (63.5 x 23 mm, 2 layers, DRC clean)
    - 3A path as solid top copper (BATT+, VBAT bar, LOAD) with track
    keep-outs so nothing can split it; gate stubs to vias
    - GND pours both layers with stitching; solid GND on the wire pads
    - No top copper under the BT832 body (unused LGA pads)
    - Net classes Power/Reg/Default + neck-down rule for fine-pitch pads
    - Routed with Freerouting via route_pcb.py (prep/finish/stitch/cleanup);
    39 vias, ~630 mm of track
    - Placement tweaks for routability: LED driver to the top next to the
    VBAT bar, regulator loop tightened (L1/C4/C3/R3 orientation), R15/R16
    rotated
    DRC: 0 violations, 0 unconnected, full schematic parity.
    Co-Authored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
    [heimdall-switch.kicad_pcb]
2026-10-01 Main PCB: J1 to the top, widen the VBAT bar for servo stall currents
    - J1 (debug header) moved to the top at the right end, above J4: the
    bottom side now carries only flat SMD parts
    - VBAT bar widened to ~7mm into the copper under Q3/Q4; Q3's gate now
    leaves through a via right above its pad instead of a stub across the
    bar (the old stub left ~1.3mm of copper in the load path)
    - Q2's VBAT fed from its own via in the bar
    - Documented expected servo stall currents and the copper capacity
    (5A continuous / 15A peaks target; ~8-10A continuous on 1oz)
    - Re-routed: 30 vias, DRC 0 violations, 0 unconnected, full parity
    [heimdall-switch.kicad_pcb]
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2026-10-01 BOM: swap out-of-stock C3 (C89632) and R4 (C98220)
    C13585 and C25804 are out of stock at LCSC. C3 becomes CL31B106KBHNNNE
    (10uF 50V X7R 1206, less DC-bias loss than the X5R), R4 the Yageo
    RC0603FR-0710KL 10k.
    [heimdall-switch.kicad_pcb, heimdall-switch.kicad_sch]
2026-10-01 J1: Tag-Connect TC2030-NL in place of the 2x5 SWD header
    The Samtec FTSH-105 cost $1.46/board for a connector used once per
    board (to flash the DFU bootloader). The TC2030-NL footprint is pads
    plus three locating holes, no part; the TC2030-CTX-NL cable ends in the
    same ARM 10-pin socket the probes use. No-legs variant so nothing goes
    through to the populated bottom side.
    Schematic: J1 symbol swapped to Conn_ARM_SWD_TagConnect_TC2030-NL,
    labels rewired, excluded from BOM. PCB: footprint in J1's old spot,
    SWD nets re-routed with everything else locked (rotation 0 of four
    tried), +3V3 to pad 1 hand-routed. ERC/DRC clean, full parity.
    [heimdall-switch.kicad_pcb, heimdall-switch.kicad_sch]
2026-10-01 Revert "J1: Tag-Connect TC2030-NL in place of the 2x5 SWD header"
    This reverts commit dd4bac91d17cbcc49fd8600aaa5e4591b524028c.
    [heimdall-switch.kicad_pcb, heimdall-switch.kicad_sch]
2026-10-01 J1: generic 2x5 1.27mm header (hanxia C41376037) instead of Samtec
    Same ARM 10-pin SMD header at ~$0.10 instead of $1.46. Its recommended
    land pattern matches KiCad's PinHeader_2x05_P1.27mm_Vertical_SMD (same
    pad width, pitch and row gap; pads 0.1mm shorter at the outer end), so
    the footprint and routing stay. Fitted on every board: each needs SWD
    once for the bootloader.
    [heimdall-switch.kicad_pcb, heimdall-switch.kicad_sch]
2026-10-01 Main PCB: SPS-20 style wire entry, board down to 49 x 23 mm
    The loop-through relief footprints for J2/J3 took ~14mm of length. Now
    plain 0.75mm2 wire pads at the edge and a 2 x 5mm slot between the
    battery and load pairs: two tabs, each pair under its own heat shrink.
    Everything else shifted 14.5mm left as a block (zones, keep-outs and
    locked pre-routes with it). R11 moved to the top side below Q3 so
    ADC_FB can reach U1 along the bottom-edge channel; the rest re-routed
    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
    [heimdall-switch.kicad_pcb, heimdall-switch.kicad_sch]
2026-10-01 Main PCB: extend the wire tabs 4mm past the pads
    Heat shrink now grips bare board and wire insulation beyond the solder
    joints. Slot 2 x 9mm, board 53 x 23mm. DRC clean, full parity.
    [heimdall-switch.kicad_pcb]
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2026-10-01 Main PCB: solid GND connection for J4 pin 3 and LED1 pin 1
    Neighbouring traces clipped their thermal-relief spokes into a broken
    ring. Solid like the J2/J3 GND pads. DRC clean.
    [heimdall-switch.kicad_pcb]
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2026-10-02 Schematic + docs: block-by-block notes on how the circuit works
    Text note per functional block on the sheet (battery/reverse polarity,
    fail-on load switch and its off chain, load sense, regulator, MCU,
    LED/button), and a matching 'circuit at a glance' table at the top of
    the Schematic section in hardware.md. ERC clean.
    [heimdall-switch.kicad_sch]
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2026-10-02 Main PCB: second JLCDFM round, vias clear of pads
    - Q4/Q3 gate vias moved off D1's pad / away from Q3 pin 4 (the 0.7mm
    via had grown into D1's pad: 'via to pad' danger)
    - fan-out vias within 0.2mm of a pad pushed to 0.25mm (11 of 13), so
    the 0.05mm mask expansion no longer comes within 0.06mm of them
    - R14.2 / Y1.2 (the two vias that couldn't move) keep a 0 mask margin
    DRC clean, full parity.
    [heimdall-switch.kicad_pcb]
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2026-10-03 Main PCB: J4 JST-XH -> JST-GH right-angle SMD (SM03B-GHS-TB)
    J4 now sits at the right edge with its cable entry flush with the board
    edge. LED_A runs on F.Cu to LED1, J4 pin 2 reaches R16 through one via
    under the connector body, and /BTN on B.Cu no longer detours around the
    old XH holes. Rev 1 of the main board (not ordered).
    [heimdall-switch.kicad_pcb, heimdall-switch.kicad_sch]
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2026-10-03 UI board GH header, JLC top/bottom export, rev 2 docs with sourced BOM
    - UI daughter board: J1 JST-XH B3B-XH-A -> JST-GH BM03B-GHS-TBT
    (vertical SMD, back side, LCSC C161691) to match main board J4;
    re-routed, ERC/DRC clean with parity, renders regenerated.
    - jlc_export.py: separate -top/-bottom BOM+CPL sets; bottom angles
    mirrored (180 - angle) as JLC expects, rotation corrections restated
    for that; pad-centre positions; parts without LCSC number left out.
    - hardware.md: PCB layout rewritten for rev 2, BOM with board side and
    source links (LCSC/Mouser), UI board and cable BOMs, cost estimate.
    - Main board layout pictures and 3D renders regenerated for rev 2.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
    [heimdall-switch-ui.kicad_pcb, heimdall-switch-ui.kicad_sch]
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2026-10-04 Pre-order verification: ngspice power-side simulation and copper check
    - hardware/sim/run_sims.py: plug-in transient, Q3 slow turn-on stress and
    firmware window (incl. threshold spread and C7 alternatives), OFF at
    full current, fail-on/OFF-current/reverse-polarity DC, each on
    datasheet-fitted models and AOS's own AO4407A model (downloaded).
    - hardware/sim/copper.py: DC current flow in the load-path copper solved
    from the board geometry (resistance, drop, loss, current density).
    - hardware.md: Verification section with the results; corrected the
    turn-on delay (40-70ms at 3S), turn-off time and plug-in spike notes.
    No board changes needed.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
2026-10-04 hardware.md: correct the symbol-library note
    Neither BT832 nor TPS629206 is in KiCad's own libraries, but both have
    vendor symbols (Fanstel's KiCad library, TI via Ultra Librarian). Ours
    are kept; the BT832 pin map matches Fanstel's. Schematic is no longer
    a first draft.
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
